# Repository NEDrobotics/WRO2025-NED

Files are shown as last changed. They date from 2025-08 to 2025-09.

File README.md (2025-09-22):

# NEDrobotics – WRO Future Engineers 2025

This repository documents the work of **Team NEDrobotics** for the **World Robot Olympiad (WRO) 2025 Future Engineers** category.  
Our team consists of three members:

- [Nicat Vəliyev](https://www.linkedin.com/in/nicat-vəliyev-2816b3269)
- [Elnur Məmmədov](https://www.linkedin.com/in/elnurmammadovv)
- [Davud Məmmədov](https://www.linkedin.com/in/davud-məmmədov-383a292a7)

We designed, built, and programmed an autonomous vehicle capable of competing in the WRO Future Engineers challenges.  
This README explains our hardware, electronics, software modules, and the process to build and upload code to our robot.  
The goal is to make our work **clear, reproducible, and useful for other teams.**

<p> 
  <a href="https://www.labcenter.com" target="_blank">
    
  </a>

  <a href="https://www.arduino.cc/en/software" target="_blank">
    
  </a>

  <a href="https://www.tinkercad.com" target="_blank">
    
  </a>

  <a href="https://www.youtube.com/@NEDRobotics" target="_blank">
    
  </a>
</p>

---

## 📋 Contents
- 👀 [Project Overview](#project-overview)  
- 🏎️ [Hardware and Chassis Design](#hardware)  
   - 🔧 [3D Print The Parts](#3dparts)
- ⚡ [Electronics and Components](#electronics)  
   - 🔋 [Li-ion Battery and Li-Po Battery](#li-ion-and-li-po)
   - 🖥️ [Arduino Mega 2560](#arduinomega2560)
   - 👁️ [HC-SR04 Ultrasonic Sensors](#hc-sr04)
   - ⚙️ [L298N Driver and LM2596 Regulators](#l298n-and-lm2596)
   - 🛞 [Lego Wheels](#wheels)
   - 📷 [HuskyLens Pro](#huskylens)
   - 🔄 [MG90 Servos and DC Motor](#servos-and-motor)
   - ⚙️ [Lego Differential](#differential)
- 🛠️ [Wiring and Integration](#wiringandintegration)
   - 🔋 [Power Management](#powermanagement)
   - 🤖 [Arduino Pins](#arduinopins)
- 👨‍💻 [Software and Control Architecture](#software)  
   - 🖥️ [Arduino Code (Low-Level Control)](#arduino)  
   - 📷 [Vision and AI Processing](#vision)  
   - 🏎️ [Obstacle and Race Management](#obstacle)  
   - 🧠 [The robot's operating logic and code sequence](#logic)
   - ⚙️ [Pseudo code](#pseudo)
 - 💵 [Bill of Materials](#billofmaterials)
   - 📦 [Component Costs](#components)
   - 🖨️ [3D Printing Cost](#printingcost)
   - 🔩 [Other Materials (Screws, Nuts, Jumpers, Heat shrinks)](#othermaterials)
   - 💵 [Total Costs](#totalcosts)
 - 📷 [Photos and Media](#media)
   - 🏁 [The robot's mission rounds](#mission)
   - 🖼️ [Photos of the robot](#photosofrobot)
   - 📝 [The robot's electronic schematic](#schematic)
   - 🖼️ [Photos of the team](#photosofteam)
 - 🛠️ [Changes and Improvements](#changes)  
 - 🔮 [Reproducibility and Future Work](#future)
 - 📏 [Techinal Specifications](#techinal)
 - 📑 [Conclusion](#conclusion)
---

## 👀 Project Overview 
Team NEDrobotics joined the WRO Future Engineers challenge with the goal of creating a reliable and intelligent self-driving robot.  
The competition requires designing a car that can:

- Drive autonomously on a race track  
- Detect and avoid obstacles  
- Handle turns, walls, and markers  
- Demonstrate efficient use of sensors and algorithms  

Our design integrates **Arduino Mega 2560** for control, **HuskyLens Pro camera** for color recognition of traffic signs, **ultrasonic sensors** for distance detection from various targets.  
We combined **3D-printed parts, 12V DC motor, and servo-based steering** to create a modular, flexible and upgradable robot.

---

## 🏎️ Hardware and Chassis Design 
- **🔧 Chassis:** Built with 3D-printed parts for structure and flexibility  
- **🔧 Custom 3D Parts:** Hold electronics, motor, and sensors in place  
- **🔧 Motor:** One 12V DC motor for precise speed and torque control
- **🔧 Drive train:** Differential drive and steering system with LEGO parts
- **🔧 Steering:** One MG90 180° servo motor with Lego gears
- **🔧 Stability:** Low center of gravity increases balance during turns  

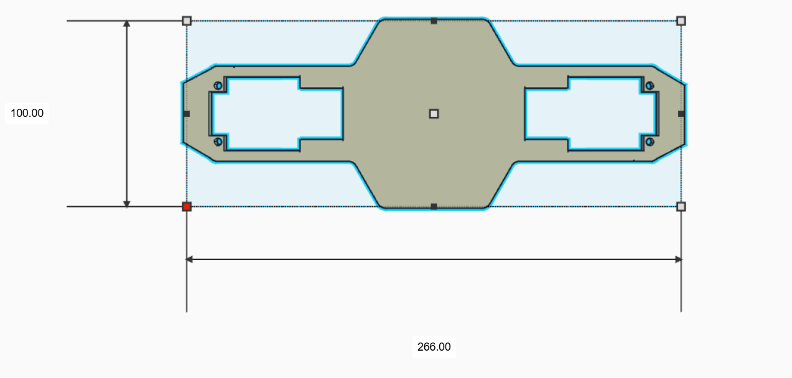
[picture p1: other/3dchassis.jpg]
3dchassis
|  | Details |
| --- | --- |
|**Dimensions:** 100x266mm |**Filament Type:** PLA |

The final build is **strong, lightweight, reliable, and modular**.

---

## ⚡ Electronics and Components 

### 🔋 Li-ion Battery and Li-Po Battery 

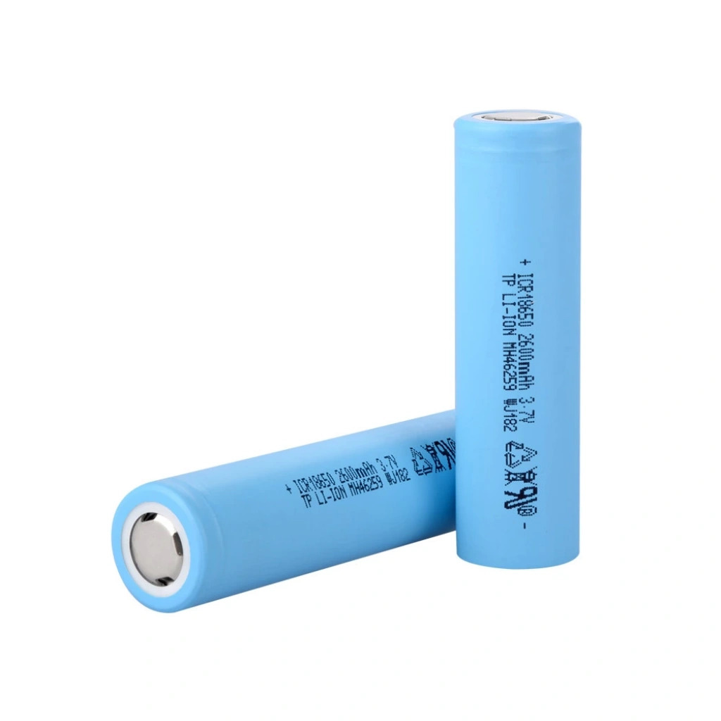
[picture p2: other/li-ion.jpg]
li-ion
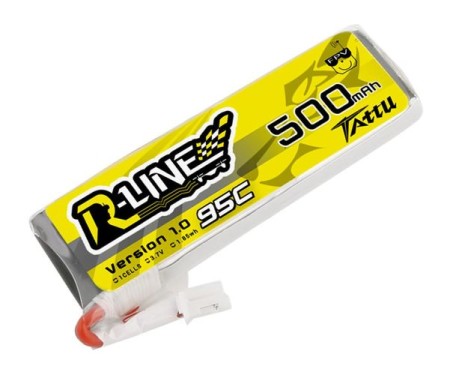
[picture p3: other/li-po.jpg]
li-po
|  |  |
| --- | --- |
|**Model:** Li-ion 18650 Battery |**Model:** 2s Li-Po Tattu Battery |
|**Voltage:** 3.7v |**Voltage:** 7.4v |
|**Weight:** 45g  |**Weight:** 31g |
|**Discharge Rate:** 2C |**Discharge Rate:** 95C |
|**Functions:** Power the motors/leds |**Functions:** Power the modules
|**Capacity:** 2600mAh |**Capacity:** 500mAh |
---
### 🖥️ Arduino Mega 2560 
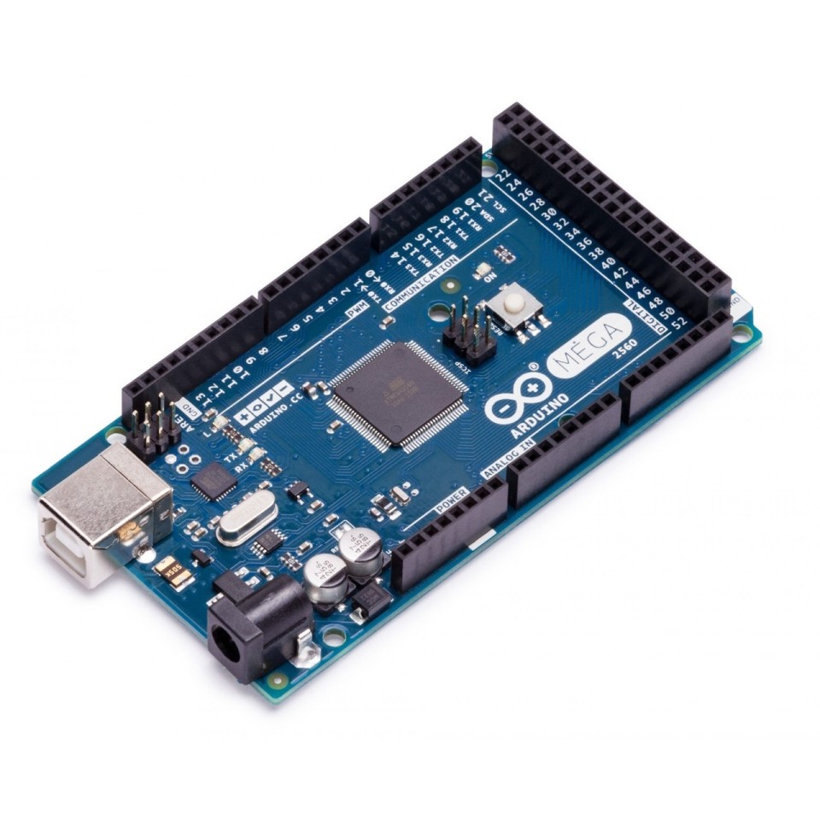
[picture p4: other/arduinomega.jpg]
arduino
|  | Details |
| --- | --- |
|**Microcontroller:** ATmega2560 |**SRAM:** 8KB |
|**Operating Voltage:** 5V |**EEPROM:** 4KB |
|**Input Voltage:** 7-12V (recomd.) |**Memory:** 256KB |
|**Digital I/O Pins:** 54 |**Clock speed:** 16 MHz |
|**PWM Pins:** 15 |**Weight:** 37g |
|**Current Draw:** 50mA |**Dimensions:** 102x53x30mm|
---
### 👁️ HC-SR04 Ultrasonic Sensors 
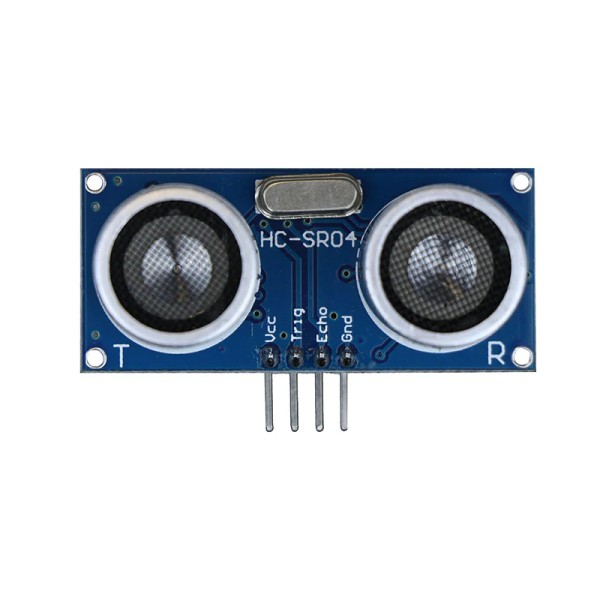
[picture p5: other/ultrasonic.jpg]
hc-sr04
|  | Details |
| --- | --- |
|**Model:** HC-SR04 |**Min range:** 2cm |
|**Operating Voltage:** 5V |**Max range:** 4m |
|**Ultrasonic Frequency:** 40Hz |**Measuring Angle:** 15 degree | 
|**Weight:** 8.5g |**Dimensions:** 45x20x15mm |
|**Current Draw:** 15mA |**Accuracy:** 0.3cm (3mm) |
---
### ⚙️ L298N Driver and LM2596 Regulators 
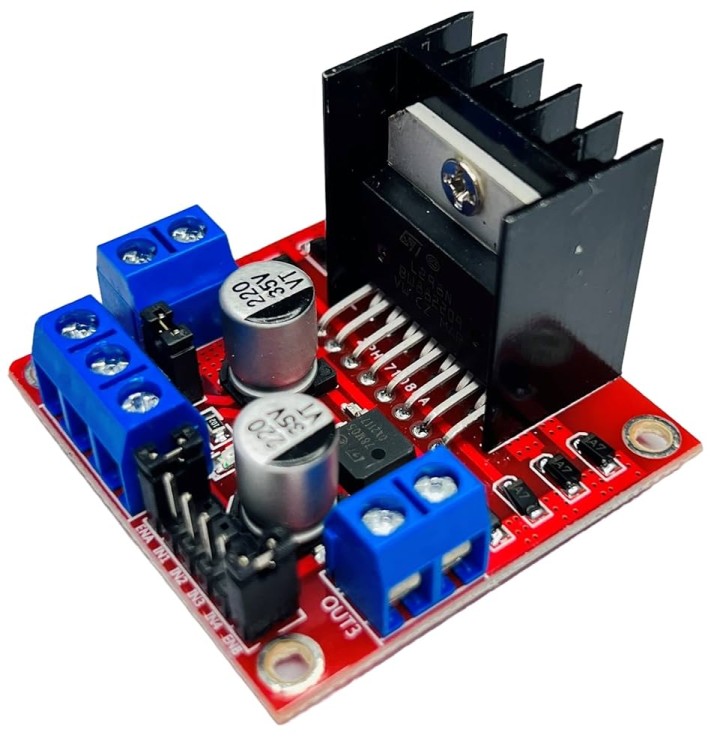
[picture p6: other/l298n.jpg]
l298n
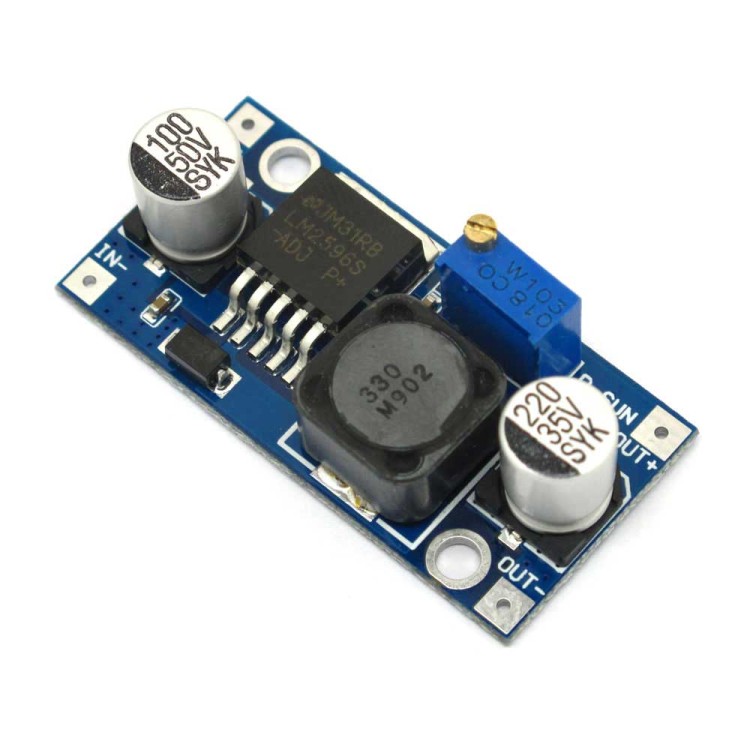
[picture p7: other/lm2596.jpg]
lm2596
|  |  |
| --- | --- |
|**Driver Model:** L298N 2A |**Model:** LM2596 Buck Converter |
|**Driver Chip:** Double H Bridge L298N |**Input Voltage:** 4V-35V |
|**Logic Voltage:** 5V |**Output Voltage:** 1.23V-30V |
|**Driver Voltage:** 5-35V |**Output Current:** 3A (max) |
|**Weight:** 25g |**Weight:** 11g |
|**Idle Current:** 36mA|**Idle Current:** 5mA
---
### 🛞 Lego Wheels
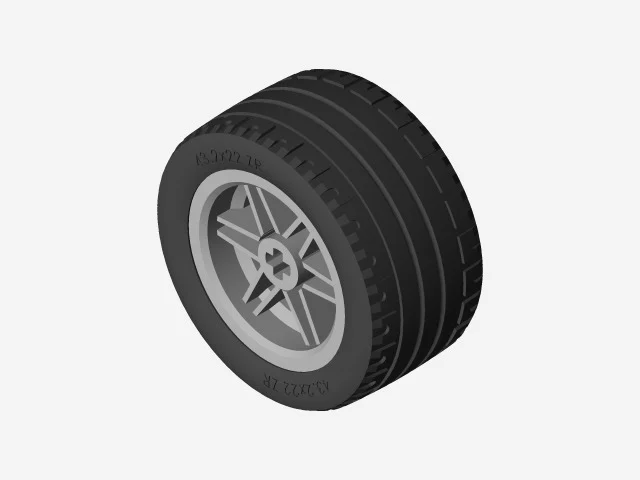
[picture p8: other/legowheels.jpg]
wheels
|  | Details |
| --- | --- |
|**Part Number:** 56145c01 |**Model Number:** 11218 |
|**Size:** 43.2x22mm |**Rim Size:** 20.66mm (0.79inches) |
|**Weight:** 59g |**Wheel Size:** 22mm |
---
### 📷 HuskyLens Pro 
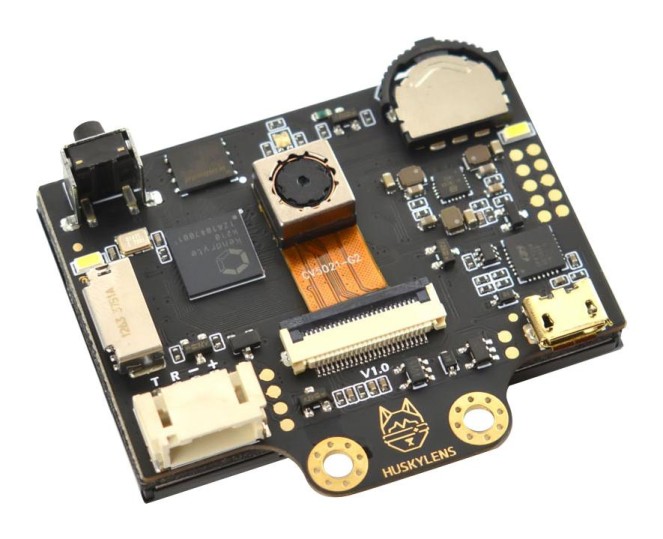
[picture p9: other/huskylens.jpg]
|  | Details |
| --- | --- |
|**SKU:** SEN0336 |**Camera:** OV5640 5.0MegaPixel |
|**Functions:** Face Recognition, Object Tracking, Object Recognition, Line Tracking, Color Recognition, Tag Recognition, Object Classification, QR Recognition, Barcode recognition | **Weight:** 40g |
|**Current Draw:** 320mA @3.3V, 230mA @5.0V | **Dimensions:** 52x44.5mm |
---
### 🔄 MG90 Servos and DC Motor 
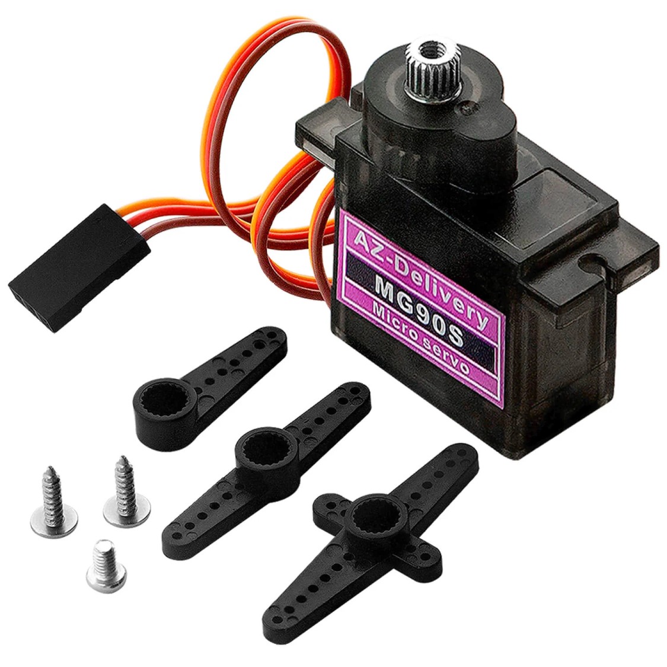
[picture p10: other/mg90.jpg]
servo
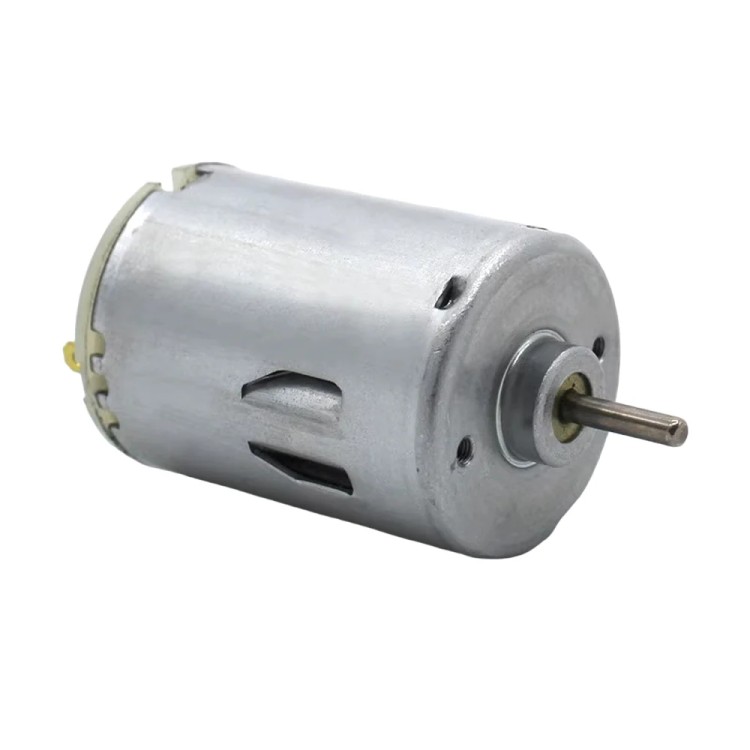
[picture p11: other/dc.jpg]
dc
|  |  |
| --- | --- |
|**Operating Voltage:** 4.8V to 6V (Typically 5V) |**Motor:** RS-280 |
|**Gear Type:** Metal |**Operating Voltage:** 6V – 12V |
|**Stall Torque:** 1.8kg/cm (4.8V) |**Body diameter:** ~24mm |
|**Max Stall Torque:** 2.2kg/cm (6V) |**Shaft diameter:**  ~2.0mm
|**Weight:** 13.4g |**Weight:** 55g (appr.) |
|**Rotation:** 0°-180° | **Torque:** 4.46mNm |
|**Rated Current:** 250mA | **Rated Current:** 280mA |
|**Stall Current:** 850mA | **Stall Current:** 1.5A |
---
### ⚙️ Lego Differential 
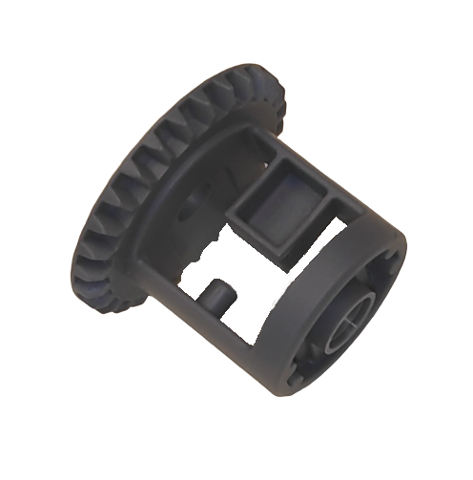
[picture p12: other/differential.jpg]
differential
|  | Details |
| --- | --- |
|**Part Number:** 62821 |**Gear Type:** 28-tooth bevel gear |
|**Weight:** 2.8g (appr.) |**Color:** Dark Bluish Gray |
---

## 🛠️ Wiring and Integration 
### 🔋 Power Management 
- **2S 18650 (Main) → XL6009 Voltage regulator (12V) & (LM2596 - B) → L298N Driver → DC Motor & LEDs**
- **2S Li-Po (Other) → (LM2596 - A) & (LM2596 - C) & (Arduino)**
- **LM2596 - A → Ultrasonic Sensors**
- **LM2596 - B → Servo**
- **LM2596 - C → HuskyLens Pro**
### 🤖 Arduino Pins 
 - **D8~ → 🛞 Motor Driver ENA**
 - **D9~ → 🛞 Motor Driver ENB** 
 - **D22 → 🛞 Motor Driver IN1** 
 - **D23 → 🛞 Motor Driver IN2** 
 - **D24 → 🛞 Motor Driver IN3** 
 - **D25 → 🛞 Motor Driver IN4** 
 - **D11~ → 🔄 Servo PWM**
 - **D16 → 📷 HuskyLens RX Pin**
 - **D17 → 📷 HuskyLens TX Pin**
 - **D44 → ⬅️ Left Ultrasonic Echo Pin**
 - **D45 → ⬅️ Left Ultrasonic Trig Pin**
 - **D46 → ➡️ Right Ultrasonic Echo Pin**
 - **D47 → ➡️ Right Ultrasonic Trig Pin**
 - **D48 → ⬆️ Front Ultrasonic Echo Pin**
 - **D49 → ⬆️ Front Ultrasonic Trig Pin**
 - **D53 → 🚩 Start Button**
 - **🚩 Start Button → GND**
###### ( ~ ) = PWM Pins
###### ( D ) = Digital Pins
 
---

## 👨‍💻 Software and Control Architecture 

### 🖥️ Arduino Code (Low-Level Control) 
- Runs on Arduino Mega  
- Handles motor control, servo steering, ultrasonic readings 
- Uses PWM and smooth acceleration  

### 📷 Vision and AI Processing 
- Managed by HuskyLens Pro  
- Detects colors of the traffic signs  
- Sends data to Arduino for decisions  

### 🏎️ Obstacle and Race Management 
- State-machine logic with behaviors:  
  - START  
  - DETERMINE DIRECTION
  - EXIT PARKING LOT
  - REPEAT UNTIL 3 LAPS COMPLETED:
    - DETECT COLOR OF THE TRAFFIC SIGN
    - TURN LEFT AND FOLLOW LEFT WALL / TURN RIGHT AND FOLLOW RIGHT WALL
    - DETECT COLOR OF THE NEXT TRAFFIC SIGN AND MAKE SUITABLE CORNER TURN
  - PARK
  - FINISH  

### 🧠 The robot's operating logic and code sequence 

 - **PID wall-following**
   - The robot uses a classic PID loop to maintain a set distance from the wall: `error = targetdistance - measured_distance` (measured from the active side ultrasonic). Readings are first smoothed with an EMA to suppress noise. The PID output (clamped to a maximum correction in degrees) is translated into servo angle offsets around `spos`; when following the right wall the output sign is inverted so a positive command always means “steer left” in code. Forward motor PWM is automatically scaled down based on how large the steering correction is, so the robot slows during aggressive steering.

 - **Ultrasonic sensors**
   - The ultrasonic sensors on the right and left sides determine how far away the robot is from the wall and in which way it should move. During the loop, if the robot is moving clockwise, it uses the data from the left sensor to orient itself (PID wall following); if it is moving counterclockwise, it uses the data from the right sensor. When it's time to turn, if the front sensor data is smaller than given threshold value, it checks both sides to learn which direction it should go then makes turn to that way, then realigns itself with **PID wall following algorithm** to move to the next turning point. *The front sensor is also checks the distance to the parking walls during parking time, enabling it to park in an orderly manner.*
 - **HuskyLens**
   - The Huskylens camera sends the colors of traffic signs it sees in the distance to the Arduino as raw data and colorID, and the Arduino processes them, enabling the robot to maneuver right or left.

 - **Motor driver**
   - The L298N motor driver allows us to control the motor's speed and direction and adjust the brightness of the LEDs.

 - **Button**
   - The button allows us to run the code.

 - **LEDs**
   - The LEDs we placed on the front side assist the huskylens, making the colors of traffic signs appear more *vivid* and easier to see.

 - **Conventors and capacitors**
   - The LM2596 regulators reduce the voltage of the power coming from the battery and send it to the sensors/husklens and other components. *The capacitors supply the sudden current surge.*
### ⚙️ Pseudo code 
<details> <summary>Click to see!</summary>

```cpp

# --- Constants / Globals ---
DEFINE pins, servo mids, motor pins, button pin
DEFINE targetdistance, Kp, Ki, Kd, I_MAX, I_MIN
DEFINE alpha, servoUpdateInterval, MAX_CORRECTION_DEG
DEFINE TURN_DEGREE, TURN_PWM, TURN_SETTLE_MS, TURN_TIMEOUT_MS
DEFINE SIDE_TURN_STOP_CM, DELTA_TO_TRIGGER, IGNORE_AFTER_TURN_MS
DEFINE BASE_SPEED, MIN_SPEED, SMALL_STEER_DEG
DEFINE TURN_SIDE_MODE (0=auto,1=left,2=right)

GLOBAL filteredLeft, filteredRight, filteredFront
GLOBAL oldLeft, oldRight, baselineLeft, baselineRight
GLOBAL integralTerm, lastError, lastPidTime
GLOBAL lastServoUpdate, lastS1pos, lastS2pos
GLOBAL ignoreUntil, turnCount, firstTurnDone, activeTurnMode

# --- Low-level helpers ---
FUNCTION readUltrasonicCm(trig, echo):
  pulse trigger, measure echo with timeout
  IF timeout return -1
  RETURN distance_cm

FUNCTION preciseSampleUltrasonics(samples=8, delayMs=20):
  read sensors multiple times, average valid readings
  assign to filteredLeft, filteredRight, filteredFront

FUNCTION stopMotors():
  set motor PWMs = 0

FUNCTION setMotorsForward(forward, speed):
  set motor driver pins and PWM for both motors (account wiring)

# --- Steering helpers ---
FUNCTION setSteerLeftMax(): write servos to s1mid+TURN_DEGREE, s2mid-TURN_DEGREE, update timestamp
FUNCTION setSteerRightMax(): write servos to s1mid-TURN_DEGREE, s2mid+TURN_DEGREE, update timestamp
FUNCTION centerSteering(): write servos to mids, update timestamp

FUNCTION rotateUntilSideUnder(side, stopCm=SIDE_TURN_STOP_CM, timeoutMs=TURN_TIMEOUT_MS):
  turnCount += 1
  steer fully to side, start motors (low then TURN_PWM)
  loop until filtered side < stopCm or timeout:
    read that side, EMA-update filtered value
  stopMotors(), delay(TURN_SETTLE_MS), centerSteering()
  preciseSampleUltrasonics()
  ignoreUntil = now + IGNORE_AFTER_TURN_MS

# --- PID ---
FUNCTION computePidOutput(measured):
  dt = max(epsilon, (now - lastPidTime)/1000)
  error = targetdistance - measured
  integralTerm = clamp(integralTerm + error*dt, I_MIN, I_MAX)
  derivative = (error - lastError)/dt
  output = Kp*error + Ki*integralTerm + Kd*derivative
  output = clamp(output, -MAX_CORRECTION_DEG, MAX_CORRECTION_DEG)
  lastError = error; lastPidTime = now
  RETURN output

FUNCTION writeServosFromOutput(output):
  rate-limit by servoUpdateInterval
  s1pos = constrain(s1mid - output,0,180)
  s2pos = constrain(s2mid + output,0,180)
  write servos, update last positions and timestamp

# --- Setup / Main loop ---
FUNCTION setup():
  Serial begin, configure pins and servos, write mids
  lastPidTime = now; lastServoUpdate = now

LOOP main:
  IF button pressed -> call testProgram()
  ELSE delay(20)

# --- Test routine (compact) ---
FUNCTION testProgram():
  WHILE turnCount < 12:
    drive forward (high speed)
    read sensors once, EMA update filtered values
    IF filteredFront < 50:
      turnCount++
      IF first-time-flag:
        preciseSampleUltrasonics(6)
        choose activeTurnMode by checking filteredLeft (if >80 then left else right)
      pulse big servo deflection toward activeTurnMode for ~800ms, return to center
    small nudge: if activeTurnMode==left and filteredRight<20 -> tiny left nudge; analogous for right
  stopMotors()

# --- Main autonomous routine (compact) ---
FUNCTION runProgram():
  delay(500); ignoreUntil=0; turnCount=0; firstTurnDone=false
  preciseSampleUltrasonics(10); baselineLeft=filteredLeft; baselineRight=filteredRight
  oldLeft = baselineLeft; oldRight = baselineRight

  determine startInMiddle if both filtered sides > 35 cm
  IF TURN_SIDE_MODE forced -> set activeTurnMode accordingly
  ELSE IF startInMiddle -> activeTurnMode = 0 (unlocked)
  ELSE activeTurnMode = side with smaller initial distance

  WHILE turnCount < 11:
    read sensors once, EMA update filteredLeft/Right/Front
    turned = false

    # 1) Auto-first-turn detection (only if AUTO mode & not done)
    IF not firstTurnDone AND TURN_SIDE_MODE==0 AND now > ignoreUntil:
      leftDelta = filteredLeft - oldLeft
      rightDelta = filteredRight - oldRight
      IF max(leftDelta, rightDelta) >= DELTA_TO_TRIGGER:
        chosenSide = side with larger delta
        preciseSampleUltrasonics(6)
        IF (filteredChosen - oldChosen) >= DELTA_TO_TRIGGER:
          activeTurnMode = chosenSide
          firstTurnDone = true
          perform simple timed servo turn toward chosenSide (short motor pulse + servo deflection)
          reset PID (integralTerm, lastError, lastPidTime)
          turned = true
          stopMotors()
          preciseSampleUltrasonics(6)

    # 2) Side-specific trigger (locked mode)
    IF not turned AND now > ignoreUntil:
      IF activeTurnMode == LEFT AND filteredLeft - oldLeft >= DELTA_TO_TRIGGER:
        preciseSampleUltrasonics(6)
        IF still triggered: rotateUntilSideUnder(LEFT); reset PID; firstTurnDone=true; turned=true
      ELSE IF activeTurnMode == RIGHT AND filteredRight - oldRight >= DELTA_TO_TRIGGER:
        analogous for RIGHT

    # 3) Normal wall-following if not turning
    IF not turned:
      beforeFirstTurn = (not firstTurnDone AND TURN_SIDE_MODE==0)
      IF beforeFirstTurn AND filteredLeft>35 AND filteredRight>35:
        centerSteering(); setMotorsForward(true, moderate_speed)
      ELSE:
        measured = (activeTurnMode==RIGHT) ? filteredRight : filteredLeft
        pidOutput = computePidOutput(measured)
        IF beforeFirstTurn: clamp pidOutput to SMALL_STEER_DEG
        servoOutput = pidOutput * (activeTurnMode==RIGHT ? -1 : 1)
        writeServosFromOutput(servoOutput)
        compute speed reduction based on |pidOutput| and setMotorsForward(true, speed)

    oldLeft = filteredLeft; oldRight = filteredRight
    delay(20)

  # finish sequence
  driveForwardStraight(120)
  apply small final servo offset then stopMotors()

# --- End of pseudocode

```

</details>

## 💵 Bill of Materials 

### 📦 Component Costs 
| Amount | Component | Notes | Prices |
|---|---|---|---|
| 1 | [Arduino Mega 2560](other/arduinomega.jpg) | Main controller | 18.2₼ (10.7$) |
| 4 | [LM2596 buck converters](other/lm2596.jpg) | Voltage regulation | 2.6₼ (1.52$) |
| 1 | [L298N motor driver](other/l298n.jpg) | Motor control | 3.5₼ (2.05$) |
| 1 | [12V DC Motor](other/dc.jpg) | Drive | Free\* |
| 3 | [Ultrasonic sensors](other/ultrasonic.jpg) | Distance measurement | 8₼ (4.7$) |
| 1 | [HuskyLens Pro AI camera](other/huskylens.jpg) | Vision | Free\* |
| 1 | [MG90 servo motor (180°)](other/mg90.jpg) | Steering | 4.5₼ (2.64$) |
| 4 | [Li-ion 18650 Battery](other/li-ion.jpg) | Power source | 19₼ (11.17$) |
| 1 | [2S Li-Po Tattu 500mAh](other/li-po.jpg) | Power source | Free\* |
| 1 | [2x18650 Battery Holder](other/holder.jpg) | Misc | 4.3₼ (2.52$) |
| 1 | [Lithium Batter charger](other/charger.jpg) | Misc | 13.9₼ (8.17$) |
| 3 | [LEDs](other/light.jpg) | Misc | Free\* |
| 1 | [16v 4700µ Capacitor](other/16v.jpg) | Misc | 3₼ (1.76$) |
| 2 | [25v 4700µ Capacitors](other/25v.jpg) | Misc | 3.5₼ (2.05$) |
| - | - | - | - |
| **Total Component Cost:** | - | - | **80.5₼ (47.3$)**

### 🖨️ 3D Printing Cost 
| Amount | Name | Notes | Prices |
| --- | ---- | ----- | --- |
| 1000g | 1.75mm PLA Filament | Material | 44.2₼ (26$) |
| **Total Printing Cost:** | - | - | **44.2₼ (26$)** |

### 🔩 Other Materials (Screws, Nuts, Jumpers, Heat shrink) 
| Amount | Name | Notes | Prices |
| --- | ---- | ----- | --- |
| 120 | Jumpers | Cables | 3₼ (1.76$) |
| 8 | Nuts | Fasteners | Free\* |
| 2meter | Heat Shrinks | Fasteners | Free\* |
| **Total Other Materials Cost:** | - | - | **3₼ (1.76$)** |

### 💵 Total Costs 
| Category | Notes | Prices |
| --- | ---- | ----- |
| Components | - | 80.5₼ (47.3$) |
| 3D Printing | - | 44.2₼ (26$) |
| Other Materials | - | 3₼ (1.76$) |
|**Total Cost:** | - | **127.7₼ (74.7$)** |

##### We paid 70₼ (41.1$) for the map, and we already had the boards for the walls, which we painted with black spray paint.
###### \*Items marked with “Free” are parts that we had in previous races.
##### Engineering is not about creating something with unlimited resources, it's about creating wonders with the resources you have!
---

## 📷 Photos and Media 
### 🏁 The robot's mission rounds *( /videos )* 
<p> 
  <a href="https://youtube.com/shorts/DDyiXAjG3tE?feature=share" target="_blank">
    
  </a>

  <a href="https://youtu.be/Fkb7Ndxywkc" target="_blank">
    
  </a>
</p>

### 🖼️ Photos of the robot *( /v-photos )* 

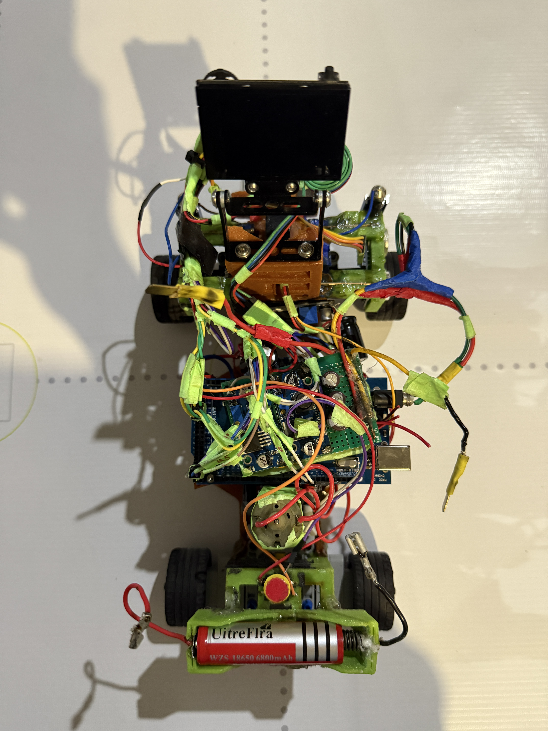
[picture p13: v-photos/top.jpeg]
The **top** of the robot
  
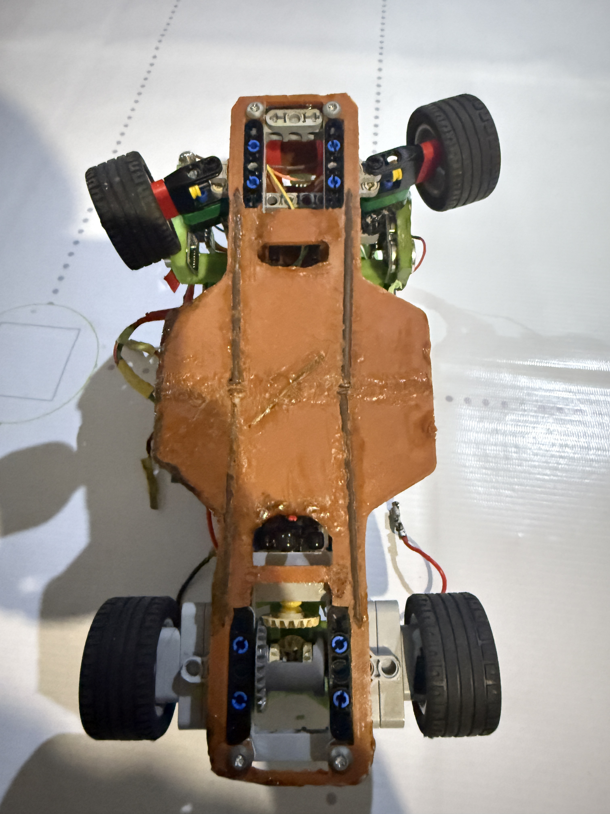
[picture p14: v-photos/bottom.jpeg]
The **bottom** of the robot

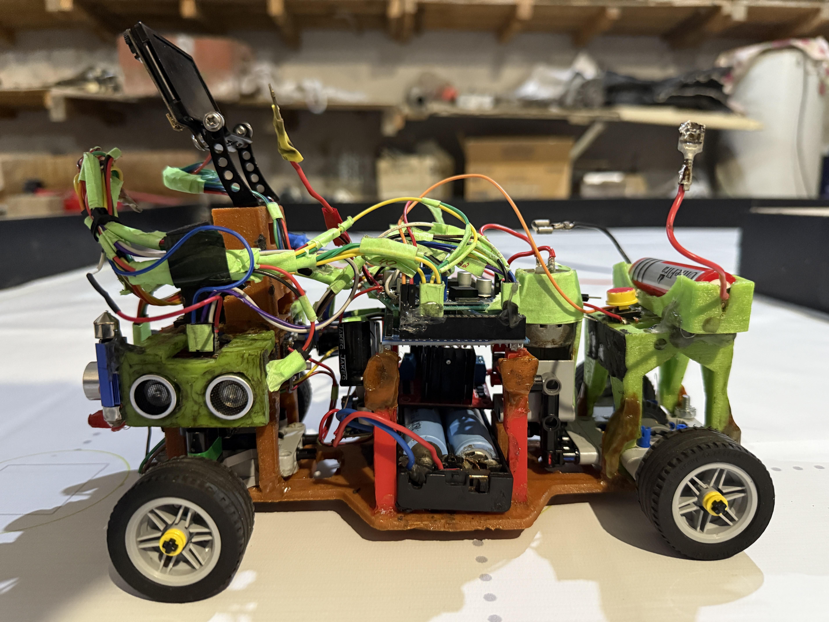
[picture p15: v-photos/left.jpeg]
The **left side** of the robot
    
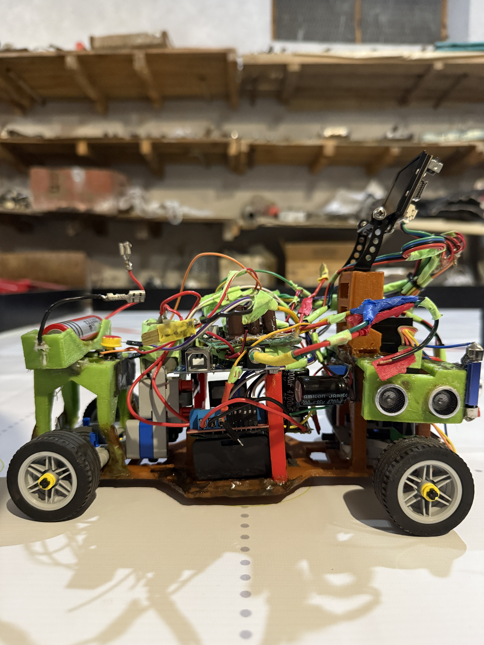
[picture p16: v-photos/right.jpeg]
The **right side** of the robot
  
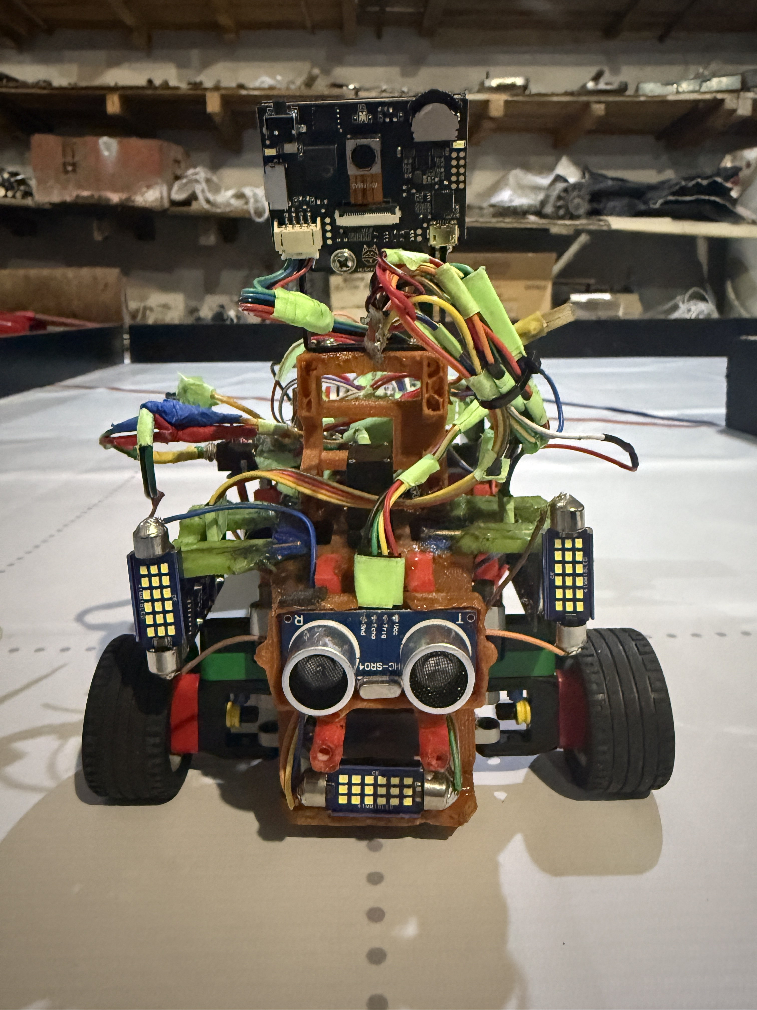
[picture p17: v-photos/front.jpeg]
The **front** of the robot

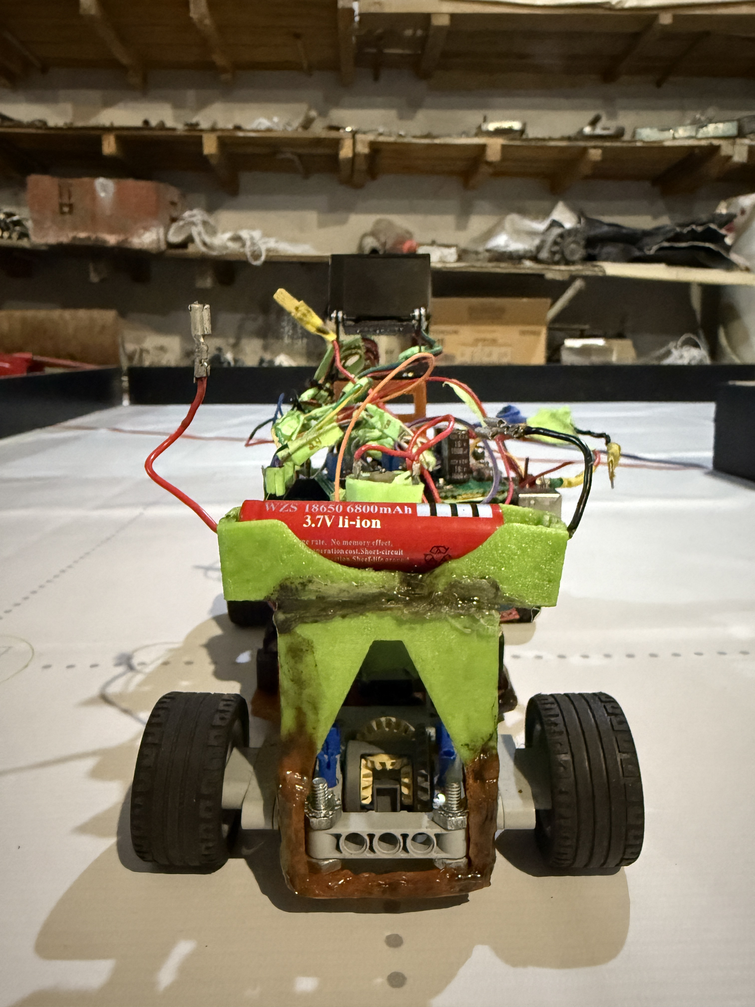
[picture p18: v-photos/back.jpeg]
The **back** of the robot
   

### 📝 The robot's electronic schematic  *( /schemes )* 
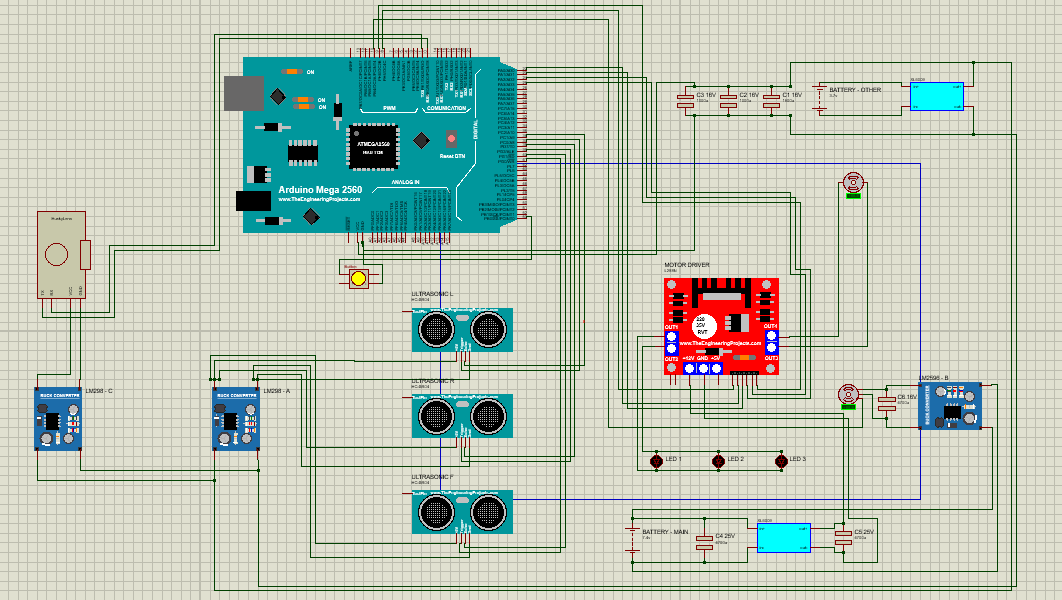
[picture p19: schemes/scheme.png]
The **scheme** of the robot
 

### 🖼️ Photos of the team *( /t-photos )* 
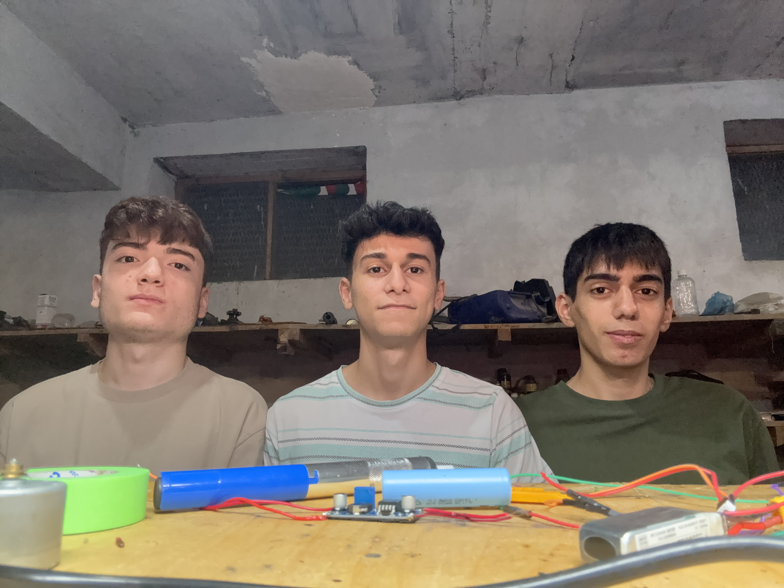
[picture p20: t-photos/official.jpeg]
Team photo
 
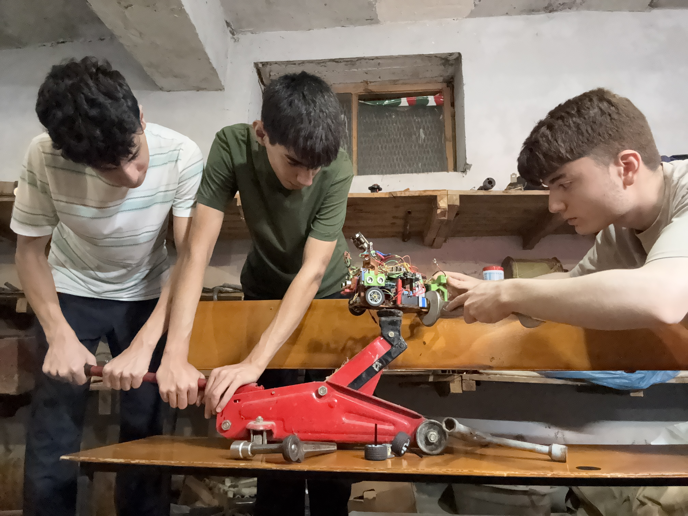
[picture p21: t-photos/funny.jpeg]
Funny photo
 

---

## 🛠️ Changes and Improvements 
During development we made important modifications:  

- ✔  Since the color sensor did not work very well and **the values it provided could not be very accurate**, we decided to remove the **TCS3200** from the robot. 

- ✔  Although the distance between the robot and the wall was small, the ultrasonic sensors perceived the distance as **far** because they were facing the wall **at an angle** slightly below it. This caused the robot to approach the wall **even closer**, leading to errors. While searching for a practical solution in the robot's driving algorithm, we added various automation algorithms such as the **PID** driving algorithm. Finally, to further improve performance, we decided to place the ultrasonic sensors **on the front of the robot.**

- ✔   We updated our HuskyLens camera with *HUSKYLENSWithModelV0.5.1bNorm* so it can better distinguish object colors and operate with fewer errors. The newer version slightly improved color recognition performance on the robot.

- ✔   We made the robot **rear-wheel drive** to **minimize the friction force** on the wheels and make it more **stable** and **powerful**. 

- ✔   Previously, there were no LEDs in front of the robot. Later, through experience, we realized that **it couldn't fully identify the colors of traffic signs**, so we placed three powerful **LEDs** on the front.

- ✔  Initially, we used **a single power source for the entire system**, but this later caused a number of problems. The reason for this was that the motor drew a sudden surge of current during startup, causing **voltage sag**. As a result, the Arduino and other modules would shut down and restart. As a solution, we **separated the power sources** for the motors (drive and servo motors). We also added **three capacitors** to handle the current demand **at peak times.** 
---
## 🔮 Reproducibility and Future Work 
We aim to make our robot easy to reproduce.  
This repository includes source code, wiring diagrams, and 3D files.  

Future improvements:  
- ⏳ Upgrade motor for higher speed  
- ⏳ Use more advanced **AI camera system**
- ⏳ Improve overall performance quality
- ⏳ Use more **precise** sensors
- ⏳ **Shortening** the robot's sizes 
- ⏳ Use more **powerful** and more **efficient** batteries

###### The road goes to success is always under construction.
---
## 📏 Technical specifications 
 - **Dimensions:** 275mm (L) x 168mm (W) x 200mm (H)
 - **Weight:** 727g
 - **Maximum speed:** 0.5m/s
 - **Driving system:** Rear-wheel drive (RWD)
 - **Steering Torque:** 20.6Ncm

---
## 📑 Conclusion 
Team NEDrobotics’ project shows how teamwork, electronics, and coding can solve the WRO Future Engineers challenge.  
We created a **reliable, modular, and efficient autonomous robot** with Arduino, HuskyLens, and Lego EV3.  
This repository is a **complete guide** for anyone who wants to understand, rebuild, or improve our design.

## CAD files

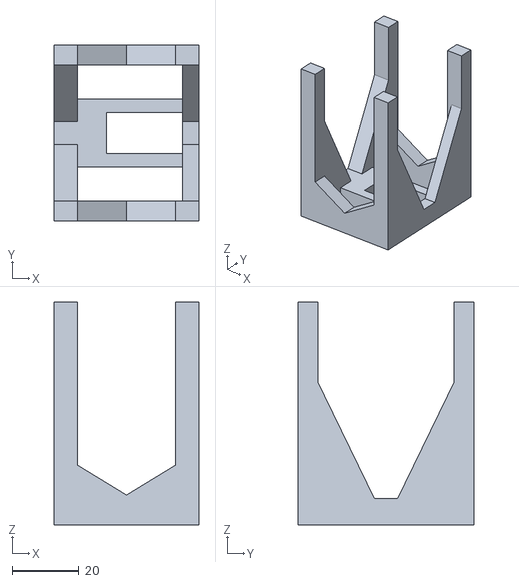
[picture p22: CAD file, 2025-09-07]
models/servohub.stl
43.5 x 53.0 x 67.0

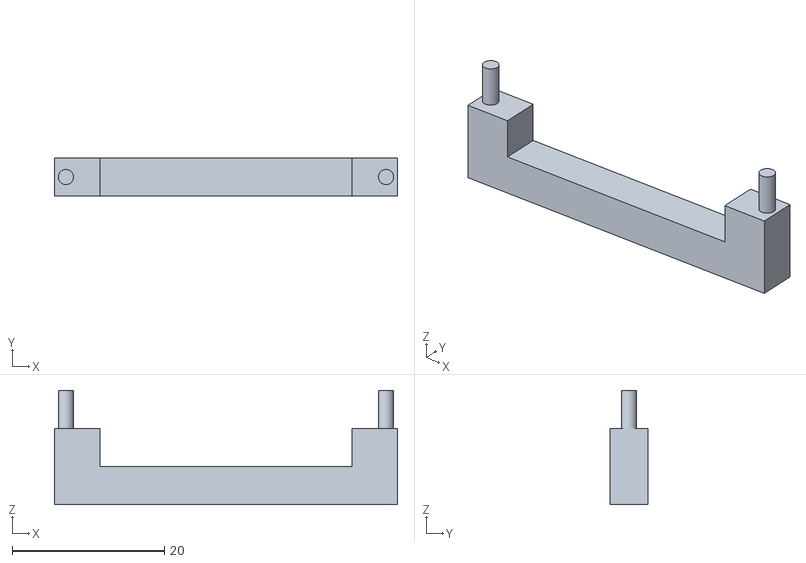
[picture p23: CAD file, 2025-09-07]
models/ultrasonic-holder-v2.stl
45.0 x 5.00 x 15.0

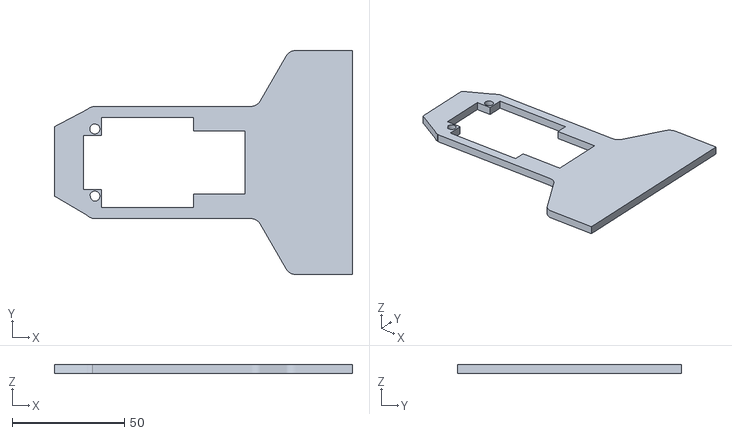
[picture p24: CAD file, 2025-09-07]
models/robotbody.stl
133.0 x 100.0 x 4.00

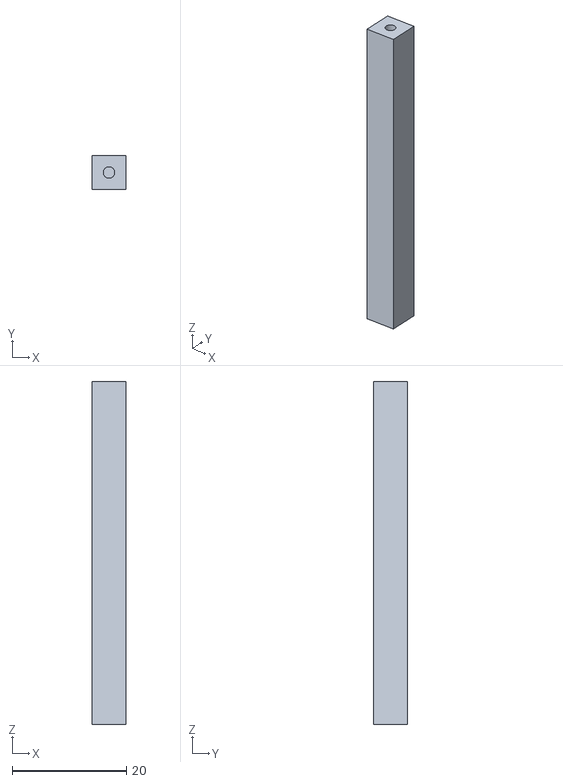
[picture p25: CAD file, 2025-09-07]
models/arduinoholder.stl
6.00 x 6.00 x 60.0

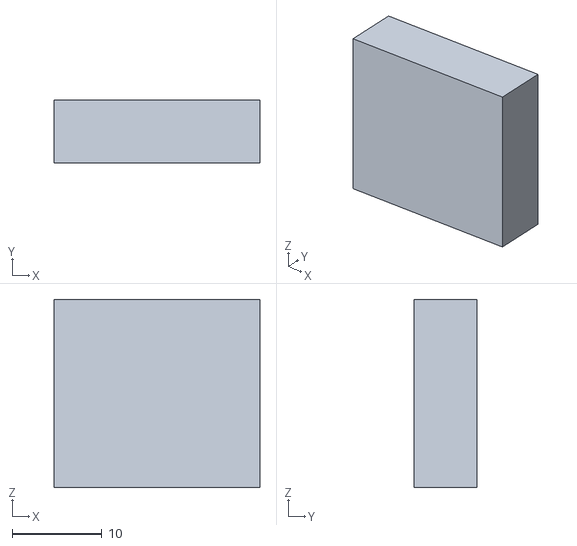
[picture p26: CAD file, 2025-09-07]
models/motorholder.stl
23.0 x 7.00 x 21.0

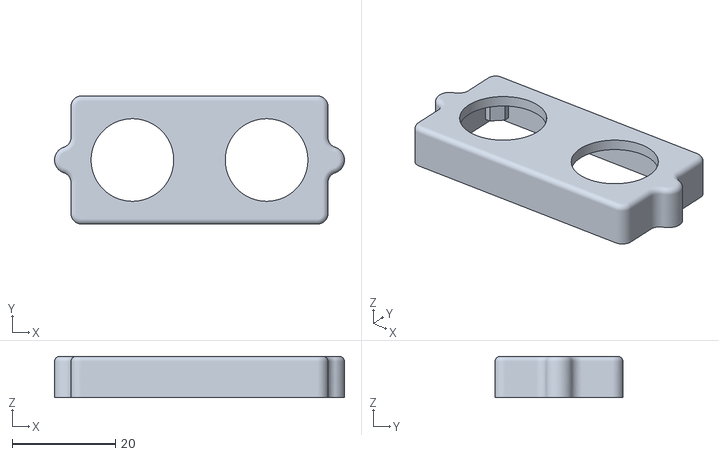
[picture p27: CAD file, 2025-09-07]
models/ultrasonic-holder-top-v1.stl
56.2 x 24.8 x 8.00

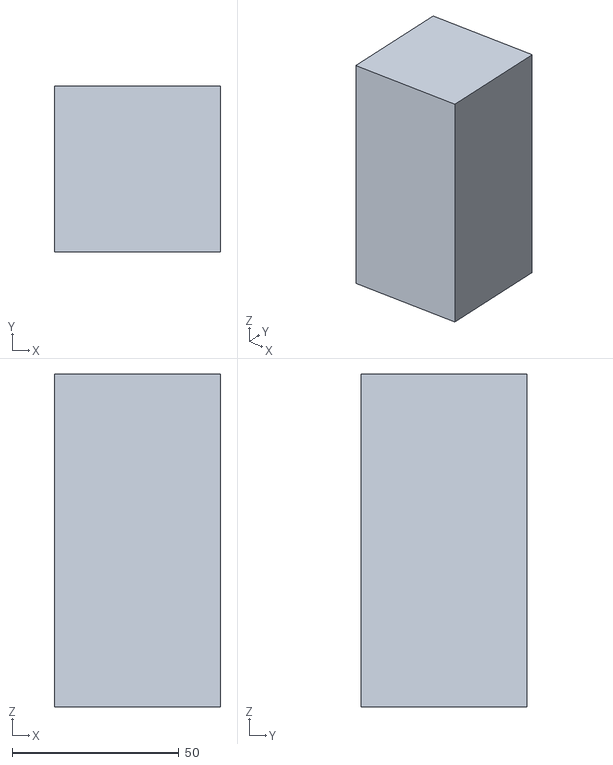
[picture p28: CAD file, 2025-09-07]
models/cubes.stl
50.0 x 50.0 x 100.0

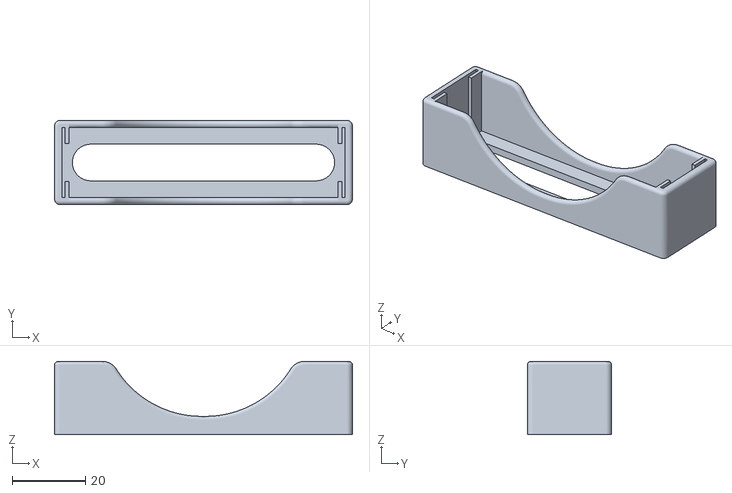
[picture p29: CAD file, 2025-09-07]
models/bottombatteryholder.stl
81.4 x 23.0 x 20.0

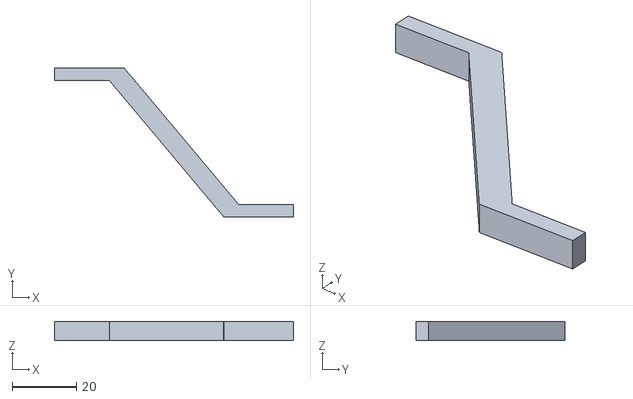
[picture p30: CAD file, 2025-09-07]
models/colorsensorholder.stl
74.4 x 46.3 x 6.00

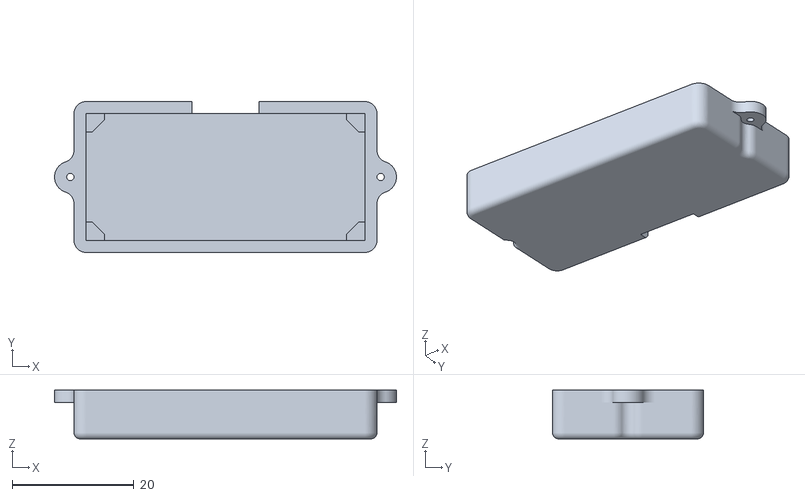
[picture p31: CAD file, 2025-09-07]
models/ultrasonic-holder-bottom-v1.stl
56.2 x 24.8 x 8.00

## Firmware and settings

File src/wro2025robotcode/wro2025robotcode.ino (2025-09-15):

#include <Servo.h>
#include <math.h>

// ---------------- HW & pins ----------------
Servo servo2;

// Left ultrasonic
const int TRIG_LEFT_PIN = 45;
const int ECHO_LEFT_PIN = 44;
// Right ultrasonic
const int TRIG_RIGHT_PIN = 47;
const int ECHO_RIGHT_PIN = 46;
// Front ultrasonic (kept but not used for turning here)
const int TRIG_FRONT_PIN = 49;
const int ECHO_FRONT_PIN = 48;

const int S2PIN = 11;
const int buttonPin = 53;
int buttonState = 0;

// Motor Driver pins
const int IN1_1 = 22;
const int IN2_1 = 23;
const int ENA_1  = 8;
const int IN1_2 = 24;
const int IN2_2 = 25;
const int ENA_2  = 9;

// servo mid positions
const int s2mid = 115;

// ---------------- control params ----------------
// wall-following target (left or right depending on active mode)
const int targetdistance = 20; // cm

// PID params (tune)
float Kp = 2.5;
float Ki = 0.0;
float Kd = 0.6;

float integralTerm = 0.0;
float lastError = 0.0;
unsigned long lastPidTime = 0;

const float I_MAX = 100.0;
const float I_MIN = -100.0;

float filteredLeft = (float)targetdistance;
float filteredRight = 1000.0f;
float filteredFront = 1000.0f;
const float alpha = 0.3f;

unsigned long lastServoUpdate = 0;
const unsigned long servoUpdateInterval = 50;

const int MAX_CORRECTION_DEG = 25;

// steering degree used for hard steer (positive is left steer magnitude)
const int TURN_DEGREE = 45;

// Very small steering used during first lap before first turn (3-5 degrees)
const int SMALL_STEER_DEG = 9;

// speeds
const int BASE_SPEED = 120;
const int MIN_SPEED = 80;

// Turning / safety
const int TURN_PWM = 59;
const int TURN_SETTLE_MS = 120;
const float SIDE_TURN_STOP_CM = 20.0f;
const unsigned long TURN_TIMEOUT_MS = 5000UL; // safety timeout

// how much bigger than the previous reading is required to trigger a turn
const float DELTA_TO_TRIGGER = 20.0f; // cm

// short ignore after a rotation to avoid immediate retrigger
const unsigned long IGNORE_AFTER_TURN_MS = 1200UL;
unsigned long ignoreUntil = 0;

// misc
int lastS2pos = s2mid;
int turnCount = 0;

// ---------- Choose turn side mode (compile-time preference) ----------
// 0 = auto-detect on first trigger (recommended) -> will lock after first turn
// 1 = left-only from start
// 2 = right-only from start
const int TURN_SIDE_MODE = 0; // set to 0,1,2 as needed (1, 2 debug mode only)

// runtime-active mode (1=left, 2=right). If TURN_SIDE_MODE==0 we pick initial follow side based on closeness.
int activeTurnMode = 0;

// store baseline readings taken at start of runProgram() (kept for diagnostics)
float baselineLeft = 0.0f;
float baselineRight = 0.0f;
bool firstTurnDone = false;

// store previous filtered values to detect sudden increase (current - prev)
float oldLeft = 0.0f;
float oldRight = 0.0f;

// ---------------- helpers ----------------

// Helper: ultrasonic reading (cm) or -1 on timeout
float readUltrasonicCm(int trigPin, int echoPin) {
  unsigned long duration = 0;
  digitalWrite(trigPin, LOW);
  delayMicroseconds(2);
  digitalWrite(trigPin, HIGH);
  delayMicroseconds(10);
  digitalWrite(trigPin, LOW);
  duration = pulseIn(echoPin, HIGH, 30000UL); // 30 ms timeout
  if (duration == 0) return -1.0f;
  return (float)duration * 0.0343f / 2.0f; // cm
}

// Precise averaged ultrasonic sampling to confirm state
void preciseSampleUltrasonics(int samples = 8, int delayMs = 20) {
  float sumL = 0.0f, sumR = 0.0f, sumF = 0.0f;
  int countL = 0, countR = 0, countF = 0;
  for (int i = 0; i < samples; ++i) {
    float vL = readUltrasonicCm(TRIG_LEFT_PIN, ECHO_LEFT_PIN);
    float vR = readUltrasonicCm(TRIG_RIGHT_PIN, ECHO_RIGHT_PIN);
    float vF = readUltrasonicCm(TRIG_FRONT_PIN, ECHO_FRONT_PIN);
    if (vL >= 0.0f) { sumL += vL; ++countL; }
    if (vR >= 0.0f) { sumR += vR; ++countR; }
    if (vF >= 0.0f) { sumF += vF; ++countF; }
    delay(delayMs);
  }
  if (countL > 0) filteredLeft = sumL / countL;
  if (countR > 0) filteredRight = sumR / countR;
  if (countF > 0) filteredFront = sumF / countF;
  Serial.print("Precise sample -> L:");
  Serial.print(filteredLeft);
  Serial.print(" R:");
  Serial.print(filteredRight);
  Serial.print(" F:");
  Serial.println(filteredFront);
}

// Stop both motors
void stopMotors() {
  analogWrite(ENA_1, 0);
  analogWrite(ENA_2, 0);
}

// Set both motors forward/backward
void setMotorsForward(bool forward, int speed) {
  // Motor 1
  digitalWrite(IN1_1, forward ? HIGH : LOW);
  digitalWrite(IN2_1, forward ? LOW  : HIGH);
  analogWrite(ENA_1, speed);
  // Motor 2 (reverse wiring)
  digitalWrite(IN1_2, forward ? LOW : HIGH);
  digitalWrite(IN2_2, forward ? HIGH : LOW);
  analogWrite(ENA_2, speed);
}

// ------------------------------------------------------------------
// Steering helpers for a servo-steered vehicle
// ------------------------------------------------------------------

void setSteerLeftMax() {
  int rightPose = constrain(s2mid - TURN_DEGREE, 0, 180);
  servo2.write(rightPose);
  lastServoUpdate = millis();
}

void setSteerRightMax() {
  int rightPose = constrain(s2mid + TURN_DEGREE, 0, 180);
  servo2.write(rightPose);
  lastServoUpdate = millis();
}

void centerSteering() {
  servo2.write(s2mid);
  lastServoUpdate = millis();
  delay(10);
}

// Rotate/turn toward a side (1=left, 2=right) by steering + driving forward until that side sensor reads < stopCm
void rotateUntilSideUnder(int side, float stopCm = SIDE_TURN_STOP_CM, unsigned long timeoutMs = TURN_TIMEOUT_MS) {
  turnCount++;
  Serial.print("steering-");
  Serial.print(side == 1 ? "LEFT" : "RIGHT");
  Serial.print(" until side < ");
  Serial.print(stopCm);
  Serial.print(" cm (timeout ");
  Serial.print(timeoutMs);
  Serial.println(" ms)");

  if (side == 1) setSteerLeftMax();
  else setSteerRightMax();
  delay(60);

  setMotorsForward(true, MIN_SPEED);
  delay(150);
  unsigned long start = millis();
  setMotorsForward(true, TURN_PWM);

  const float alphaTurn = 0.45f;
  while (true) {
    float v = -1.0f;
    if (side == 1) v = readUltrasonicCm(TRIG_LEFT_PIN, ECHO_LEFT_PIN);
    else v = readUltrasonicCm(TRIG_RIGHT_PIN, ECHO_RIGHT_PIN);

    if (v >= 0.0f) {
      if (side == 1) filteredLeft  = alphaTurn * v + (1.0f - alphaTurn) * filteredLeft;
      else           filteredRight = alphaTurn * v + (1.0f - alphaTurn) * filteredRight;
    }

    float checkVal = (side == 1) ? filteredLeft : filteredRight;
    if (checkVal < stopCm) {
      Serial.print("steer stop: side reading=");
      Serial.println(checkVal);
      break;
    }

    if ((millis() - start) > timeoutMs) {
      Serial.println("steer timeout reached — stopping");
      break;
    }

    delay(10);
  }

  stopMotors();
  delay(TURN_SETTLE_MS);
  centerSteering();
  preciseSampleUltrasonics(8, 20);

  // ignore re-trigger for a short window
  ignoreUntil = millis() + IGNORE_AFTER_TURN_MS;
}

// Drive straight with servos centered and motor pwm
void driveForwardStraight(int motorPwm) {
  if ((millis() - lastServoUpdate) >= servoUpdateInterval) {
    servo2.write(s2mid);
    lastServoUpdate = millis();
  }
  setMotorsForward(true, motorPwm);
}

// PID for wall-following: by default follows left unless activeTurnMode==2 (follow right)
float computePidOutput(float measured) {
  unsigned long now = millis();
  float dt = (now - lastPidTime) / 1000.0f;
  if (dt <= 0.0f) dt = 0.001f;

  float error = (float)targetdistance - measured;

  integralTerm += error * dt;
  if (integralTerm > I_MAX) integralTerm = I_MAX;
  if (integralTerm < I_MIN) integralTerm = I_MIN;

  float derivative = (error - lastError) / dt;
  float output = Kp * error + Ki * integralTerm + Kd * derivative;

  if (output > MAX_CORRECTION_DEG) output = MAX_CORRECTION_DEG;
  if (output < -MAX_CORRECTION_DEG) output = -MAX_CORRECTION_DEG;

  lastError = error;
  lastPidTime = now;
  return output;
}

// servo write (rate-limited)
void writeServosFromOutput(float output) {
  unsigned long now = millis();
  if ((now - lastServoUpdate) < servoUpdateInterval) return;

  int s2pos = (int)roundf((float)s2mid + output);
  s2pos = constrain(s2pos, 0, 180);

  servo2.write(s2pos);

  lastS2pos = s2pos;
  lastServoUpdate = now;

  Serial.print("Servo s2:");
  Serial.println(s2pos);
}

// ------------------ setup & loop ------------------

void setup() {
  Serial.begin(115200);
  while (!Serial) {}

  Serial.println("ready (sensor-driven turning)");
  Serial.print("TURN_SIDE_MODE compile-time = ");
  if (TURN_SIDE_MODE == 0) Serial.println("AUTO (0)");
  else if (TURN_SIDE_MODE == 1) Serial.println("LEFT-only (1)");
  else Serial.println("RIGHT-only (2)");

  pinMode(buttonPin, INPUT_PULLUP);

  pinMode(TRIG_LEFT_PIN, OUTPUT);
  pinMode(ECHO_LEFT_PIN, INPUT);
  pinMode(TRIG_RIGHT_PIN, OUTPUT);
  pinMode(ECHO_RIGHT_PIN, INPUT);
  pinMode(TRIG_FRONT_PIN, OUTPUT);
  pinMode(ECHO_FRONT_PIN, INPUT);

  servo2.attach(S2PIN);

  pinMode(IN1_1, OUTPUT);
  pinMode(IN2_1, OUTPUT);
  pinMode(ENA_1, OUTPUT);
  pinMode(IN1_2, OUTPUT);
  pinMode(IN2_2, OUTPUT);
  pinMode(ENA_2, OUTPUT);

  servo2.write(s2mid);

  lastPidTime = millis();
  lastServoUpdate = millis();
}

void loop() {
  buttonState = digitalRead(buttonPin);
  if (buttonState == LOW) {
    testProgram();
  } else {
    delay(20);
  }
}



void updateSensors(){
  float leftDist = readUltrasonicCm(TRIG_LEFT_PIN, ECHO_LEFT_PIN);
  float rightDist = readUltrasonicCm(TRIG_RIGHT_PIN, ECHO_RIGHT_PIN);
  float frontDist = readUltrasonicCm(TRIG_FRONT_PIN, ECHO_FRONT_PIN);

  if (leftDist >= 0.0f) filteredLeft = (alpha * leftDist) + ((1.0f - alpha) * filteredLeft);
  if (rightDist >= 0.0f) filteredRight = (alpha * rightDist) + ((1.0f - alpha) * filteredRight);
  if (frontDist >= 0.0f) filteredFront = (alpha * frontDist) + ((1.0f - alpha) * filteredFront);
}



int turningMode = 0;
// Blocking: runs the control loop for durationMs, then stops motors.
void driveForMs_blocking(unsigned long durationMs, void (*updateSensors)() = nullptr) {
  unsigned long start = millis();
  while (millis() - start < durationMs) {
    if (updateSensors) updateSensors(); // optional refresh of filteredLeft/Right

    // --- your original control logic ---
    float useMeasured = (turningMode == 2) ? filteredLeft : filteredRight;
    float pidOutput = computePidOutput(useMeasured);

    float servoOutput = pidOutput * ((turningMode == 2) ? 1.0f : -1.0f);
    writeServosFromOutput(servoOutput);

    int absOut = (int)abs(pidOutput);
    float frac = (float)absOut / (float)MAX_CORRECTION_DEG;
    if (frac > 1.0f) frac = 1.0f;
    float reduction = frac * 0.6f;
    int speed = (int)roundf((float)BASE_SPEED * (1.0f - reduction));
    if (speed < MIN_SPEED) speed = MIN_SPEED;
    setMotorsForward(true, speed);
    // -------------------------------------

    delay(10); // small yield to avoid burning CPU; tune as needed
  }

  // stop when time elapsed
  setMotorsForward(false, 0);
}





int flag = 1;
void testProgram(){
  while(turnCount < 12){
    setMotorsForward(true, 230);
    float leftDist = readUltrasonicCm(TRIG_LEFT_PIN, ECHO_LEFT_PIN);
    float rightDist = readUltrasonicCm(TRIG_RIGHT_PIN, ECHO_RIGHT_PIN);
    float frontDist = readUltrasonicCm(TRIG_FRONT_PIN, ECHO_FRONT_PIN);

    if (leftDist >= 0.0f) filteredLeft = (alpha * leftDist) + ((1.0f - alpha) * filteredLeft);
    if (rightDist >= 0.0f) filteredRight = (alpha * rightDist) + ((1.0f - alpha) * filteredRight);
    if (frontDist >= 0.0f) filteredFront = (alpha * frontDist) + ((1.0f - alpha) * filteredFront);
    if(filteredFront < 40){
      turnCount++;
      if(flag){
        stopMotors();
        delay(20);
        preciseSampleUltrasonics(3, 20);
        delay(10);
        if(filteredLeft > 80) turningMode = 1;
        else turningMode = 2;
        flag = 0;
        setMotorsForward(true, 230);
      }
      servo2.write(s2mid - (42 * ((turningMode == 1) ? 1 : -1)));
      delay(750);
      servo2.write(s2mid);
      delay(10);
      stopMotors();
      preciseSampleUltrasonics(3,20);
      setMotorsForward(true, 230);
    }/*
    if(turningMode == 1){
      if(filteredRight < 25){
        servo2.write(s2mid - (25-filteredRight));
        delay(100);
        servo2.write(s2mid);
      }
      if(filteredLeft < 25){
        servo2.write(s2mid + (25-filteredLeft));
        delay(100);
        servo2.write(s2mid);
      }
    }
    else if(turningMode == 2){
      if(filteredLeft < 25){
        servo2.write(s2mid + (25-filteredLeft));
        delay(100); // ~5cm
        servo2.write(s2mid);
      }
      if(filteredRight < 25){
        servo2.write(s2mid - (25-filteredRight));
        delay(100);
        servo2.write(s2mid);
      }
    }*/
    if(turnCount){
      // Choose measured value for wall follow: if locked to right, follow right; otherwise follow left.
      float useMeasured = (turningMode == 2) ? filteredLeft : filteredRight;
      float pidOutput = computePidOutput(useMeasured);
  
      // If following right side, invert sign so control steering orientation stays intuitive
      float servoOutput = pidOutput * ((turningMode == 2) ? 1.0f : -1.0f);
  
      writeServosFromOutput(servoOutput);
  
      int absOut = (int)abs(pidOutput);
      float frac = (float)absOut / (float)MAX_CORRECTION_DEG;
      if (frac > 1.0f) frac = 1.0f;
      float reduction = frac * 0.6f;
      int speed = (int)roundf((float)BASE_SPEED * (1.0f - reduction));
      if (speed < MIN_SPEED) speed = MIN_SPEED;
      setMotorsForward(true, speed);
    }
  }
  driveForMs_blocking(1500, updateSensors);
  stopMotors();
}


void runProgram() {
  delay(500);
  ignoreUntil = 0;
  turnCount = 0;
  firstTurnDone = false;

  // take a few precise samples at start to establish baseline and initialize old values
  preciseSampleUltrasonics(10, 20);
  baselineLeft = filteredLeft;
  baselineRight = filteredRight;
  oldLeft = baselineLeft;   // IMPORTANT: initialize previous-reading storage here
  oldRight = baselineRight;
  Serial.print("baselineLeft="); Serial.print(baselineLeft);
  Serial.print(" baselineRight="); Serial.println(baselineRight);

  // detect if we start in the middle (AUTO mode only)
  bool startInMiddle = false;
  if (TURN_SIDE_MODE == 0 && filteredLeft > 35.0f && filteredRight > 35.0f) {
    startInMiddle = true;
    Serial.println("START: robot appears centered between walls -> will drive straight until first turn");
  }

  // activeTurnMode initially:
  // if user forced LEFT-only or RIGHT-only, respect that.
  // if AUTO (0) -> choose the sensor that is *closest* to the wall (smaller distance),
  // unless startInMiddle is true (then we remain unlocked until first trigger and drive straight).
  if (TURN_SIDE_MODE == 1) activeTurnMode = 1;
  else if (TURN_SIDE_MODE == 2) activeTurnMode = 2;
  else {
    if (startInMiddle) activeTurnMode = 0; // unlocked; we'll drive straight until first turn
    else activeTurnMode = (filteredLeft <= filteredRight) ? 1 : 2;
    Serial.print("Initial follow chosen = ");
    if (activeTurnMode == 0) Serial.println("NONE (start in middle)");
    else Serial.println(activeTurnMode == 1 ? "LEFT" : "RIGHT");
  }


  while (turnCount < 11) {
    // read sonars (fast single readings + EMA update)
    float leftDist = readUltrasonicCm(TRIG_LEFT_PIN, ECHO_LEFT_PIN);
    float rightDist = readUltrasonicCm(TRIG_RIGHT_PIN, ECHO_RIGHT_PIN);
    float frontDist = readUltrasonicCm(TRIG_FRONT_PIN, ECHO_FRONT_PIN);

    if (leftDist >= 0.0f) filteredLeft = (alpha * leftDist) + ((1.0f - alpha) * filteredLeft);
    if (rightDist >= 0.0f) filteredRight = (alpha * rightDist) + ((1.0f - alpha) * filteredRight);
    if (frontDist >= 0.0f) filteredFront = (alpha * frontDist) + ((1.0f - alpha) * filteredFront);

    Serial.print("L:"); Serial.print(filteredLeft);
    Serial.print("  R:"); Serial.print(filteredRight);
    Serial.print("  F:"); Serial.println(filteredFront);

    // Decide whether to trigger a first-turn (dynamic > previous + DELTA_TO_TRIGGER)
    bool turned = false;
    // Only allow dynamic auto-detection if compile-time mode = 0 (AUTO) and first turn not done.
    if (!firstTurnDone && TURN_SIDE_MODE == 0 && (millis() > ignoreUntil)) {
      // check both sides; compare against previous filtered reading (oldLeft/oldRight)
      float leftDelta = filteredLeft - oldLeft;
      float rightDelta = filteredRight - oldRight;

      if ((leftDelta >= DELTA_TO_TRIGGER) || (rightDelta >= DELTA_TO_TRIGGER)) {
        // choose the side with bigger delta
        int chosenSide = (leftDelta > rightDelta) ? 1 : 2;
        Serial.print("AUTO first-turn triggered by side ");
        Serial.print(chosenSide == 1 ? "LEFT" : "RIGHT");
        Serial.print(" (delta L="); Serial.print(leftDelta);
        Serial.print(" R="); Serial.print(rightDelta);
        Serial.println(" )");

        // confirm with precise sampling (compare again against previous reading stored in oldLeft/oldRight)
        preciseSampleUltrasonics(6, 20);
        float confirmVal = (chosenSide == 1) ? filteredLeft : filteredRight;
        float confirmPrev = (chosenSide == 1) ? oldLeft : oldRight;
        if (confirmVal - confirmPrev >= DELTA_TO_TRIGGER) {
          // lock the active mode to the chosen side for subsequent turns
          activeTurnMode = chosenSide;
          firstTurnDone = true;
          Serial.print("Locking activeTurnMode to ");
          Serial.println(activeTurnMode == 1 ? "LEFT" : "RIGHT");
          // perform the turn toward chosen side (steering-based)
          // rotateUntilSideUnder(chosenSide, SIDE_TURN_STOP_CM, TURN_TIMEOUT_MS);
          setMotorsForward(true, 90);
          delay(5);
          servo2.write(s2mid - (42 * ((activeTurnMode == 1) ? 1 : -1)));
          delay(1450);
          servo2.write(s2mid);
          if(filteredLeft < 30){
            delay(625 - (625 * ((activeTurnMode == 1) ? 1 : -1)));
          }
          else if(filteredRight < 30){
            delay(625 + (625 * ((activeTurnMode == 1) ? 1 : -1)));
          }
          else{
            delay(550);
          }
          integralTerm = 0.0f; lastError = 0.0f; lastPidTime = millis();
          turned = true;
          stopMotors();
          delay(10);
          preciseSampleUltrasonics(6, 20);
        } else {
          Serial.println("Auto-trigger was transient on confirm; continue.");
        }
      }
    }

    // If not turned yet and we already locked to a side (either by compile-time preference or by first auto turn),
    // use that side's trigger logic: turn when THAT side reading exceeds previous reading by DELTA_TO_TRIGGER.
    if (!turned && (millis() > ignoreUntil)) {
      if (activeTurnMode == 1) {
        // left-only active: compare to previous filtered (oldLeft)
        if (filteredLeft - oldLeft >= DELTA_TO_TRIGGER) {
          Serial.println("LEFT active-mode trigger -> turning left");
          preciseSampleUltrasonics(6, 20);
          if (filteredLeft - oldLeft >= DELTA_TO_TRIGGER) {
            rotateUntilSideUnder(1, SIDE_TURN_STOP_CM, TURN_TIMEOUT_MS);
            integralTerm = 0.0f; lastError = 0.0f; lastPidTime = millis();
            firstTurnDone = true;
            turned = true;
          }
        }
      } else if (activeTurnMode == 2) {
        // right-only active: compare to previous filtered (oldRight)
        if (filteredRight - oldRight >= DELTA_TO_TRIGGER) {
          Serial.println("RIGHT active-mode trigger -> turning right");
          preciseSampleUltrasonics(6, 20);
          if (filteredRight - oldRight >= DELTA_TO_TRIGGER) {
            rotateUntilSideUnder(2, SIDE_TURN_STOP_CM, TURN_TIMEOUT_MS);
            integralTerm = 0.0f; lastError = 0.0f; lastPidTime = millis();
            firstTurnDone = true;
            turned = true;
          }
        }
      }
    }

    if (!turned) {
      // Normal wall-follow PID when not turning.
      // Two special cases BEFORE first turn:
      // 1) if we started in the middle (startInMiddle==true), drive STRAIGHT until first turn
      // 2) otherwise, if AUTO mode and before first turn, use very small steering
      bool beforeFirstTurn = !firstTurnDone && (TURN_SIDE_MODE == 0);

      // If we started in the middle and still haven't done first turn, go straight at full speed
      if (beforeFirstTurn && (filteredLeft > 35.0f && filteredRight > 35.0f)) {
        // center and full speed
        centerSteering();
        setMotorsForward(true, 60);
      } else {
        // Choose measured value for wall follow: if locked to right, follow right; otherwise follow left.
        float useMeasured = (activeTurnMode == 2) ? filteredRight : filteredLeft;
        float pidOutput = computePidOutput(useMeasured);

        if (beforeFirstTurn) {
          // clamp pidOutput to a very small steer (SMALL_STEER_DEG)
          if (pidOutput > SMALL_STEER_DEG) pidOutput = SMALL_STEER_DEG;
          if (pidOutput < -SMALL_STEER_DEG) pidOutput = -SMALL_STEER_DEG;
        }

        // If following right side, invert sign so control steering orientation stays intuitive
        float servoOutput = pidOutput * ((activeTurnMode == 2) ? -1.0f : 1.0f);

        writeServosFromOutput(servoOutput);

        int absOut = (int)abs(pidOutput);
        float frac = (float)absOut / (float)MAX_CORRECTION_DEG;
        if (frac > 1.0f) frac = 1.0f;
        float reduction = frac * 0.6f;
        int speed = (int)roundf((float)BASE_SPEED * (1.0f - reduction));
        if (speed < MIN_SPEED) speed = MIN_SPEED;
        if(beforeFirstTurn){ 
          speed = (int)roundf((float)60 * (1.0f - reduction));
          if (speed < 57) speed = 57;
        }
        setMotorsForward(true, speed);
      }
    }

    // save previous filtered values for next-iteration delta checks
    oldLeft = filteredLeft;
    oldRight = filteredRight;

    delay(20);
  }

  // After running until turnCount limit, drive forward then stop
  driveForwardStraight(120);
  servo2.write(s2mid + (7 * ((activeTurnMode == 1) ? 1 : -1)));
  delay(1000);
  stopMotors();
}

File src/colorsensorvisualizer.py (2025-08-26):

# show_color.py
# Reads lines like "123,45,67\n" from Arduino (baud 9600) and shows the color in a Tk window.

import sys
import tkinter as tk
from tkinter import simpledialog, messagebox
import serial
import serial.tools.list_ports
import threading
import time

BAUDRATE = 9600
READ_TIMEOUT = 1.0  # seconds

def choose_port():
    ports = list(serial.tools.list_ports.comports())
    if not ports:
        return None
    print("Available serial ports:")
    for i, p in enumerate(ports):
        print(f"[{i}] {p.device} - {p.description}")
    # If running headless, pick the first. Otherwise ask user.
    try:
        index = int(input("Choose port index (number): "))
        return ports[index].device
    except Exception:
        return ports[0].device

class SerialColorReader(threading.Thread):
    def __init__(self, port, baud=BAUDRATE):
        super().__init__(daemon=True)
        self.port = port
        self.baud = baud
        self.running = False
        self.ser = None
        self.latest = (0,0,0)

    def run(self):
        try:
            self.ser = serial.Serial(self.port, self.baud, timeout=READ_TIMEOUT)
        except Exception as e:
            print("Cannot open serial port:", e)
            return
        self.running = True
        print("Serial opened:", self.port)
        # small startup delay
        time.sleep(0.2)
        while self.running:
            try:
                line = self.ser.readline().decode('utf-8', errors='ignore').strip()
                if not line:
                    continue
                # Expect format: "r,g,b"
                parts = [s.strip() for s in line.split(',') if s.strip() != '']
                if len(parts) >= 3:
                    try:
                        r = int(float(parts[0]))
                        g = int(float(parts[1]))
                        b = int(float(parts[2]))
                        # constrain
                        r = max(0, min(255, r))
                        g = max(0, min(255, g))
                        b = max(0, min(255, b))
                        self.latest = (r, g, b)
                    except ValueError:
                        # ignore parse errors
                        pass
            except Exception:
                # on any serial read error, wait a bit
                time.sleep(0.1)
        if self.ser and self.ser.is_open:
            self.ser.close()

    def stop(self):
        self.running = False

def rgb_to_hex(rgb):
    return "#{:02x}{:02x}{:02x}".format(*rgb)

def main():
    print("Make sure Arduino Serial Monitor is closed (only one program can use the port).")
    port = choose_port()
    if not port:
        messagebox.showerror("No port", "No serial ports found. Connect Arduino and try again.")
        return

    reader = SerialColorReader(port)
    reader.start()

    # Build GUI
    root = tk.Tk()
    root.title("TCS3200 Live Color Viewer")
    root.geometry("480x360")

    canvas = tk.Canvas(root, width=480, height=300)
    canvas.pack()

    info = tk.Label(root, text="Waiting for data...", font=("Helvetica", 14))
    info.pack(pady=8)

    hex_label = tk.Label(root, text="", font=("Helvetica", 12))
    hex_label.pack()

    def update_gui():
        r, g, b = reader.latest
        hexc = rgb_to_hex((r, g, b))
        canvas.configure(bg=hexc)
        info.configure(text=f"RGB: {r}, {g}, {b}")
        hex_label.configure(text=f"HEX: {hexc}")
        root.after(80, update_gui)  # refresh ~12.5 times per second

    def on_close():
        if messagebox.askokcancel("Quit", "Stop and exit?"):
            reader.stop()
            # allow thread to finish
            time.sleep(0.1)
            root.destroy()
            sys.exit(0)

    root.protocol("WM_DELETE_WINDOW", on_close)
    root.after(100, update_gui)
    root.mainloop()

if __name__ == "__main__":
    main()
